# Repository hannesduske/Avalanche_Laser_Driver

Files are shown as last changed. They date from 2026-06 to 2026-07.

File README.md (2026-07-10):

# Nanosecond Avalanche Laser Driver

This avalanche driver generates $\mathbf{2-3\ \mathrm{ns}}$ pulses with peak pulse currents up to $\mathbf{150\ \mathrm{A}}$.
The driver integrates an adjustable boost converter to generate up to $\mathbf{320\ \mathrm{V}}$ from a low-voltage supply.

<div align="center">
<table style="border: none;">
  <tr>
    <td style="text-align:center">
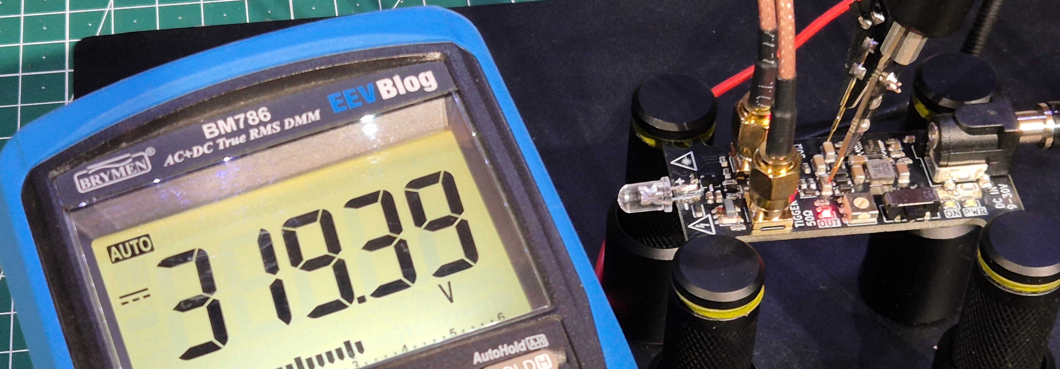
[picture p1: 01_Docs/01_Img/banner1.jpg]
      <br>
    </td>
    <td style="text-align:center">
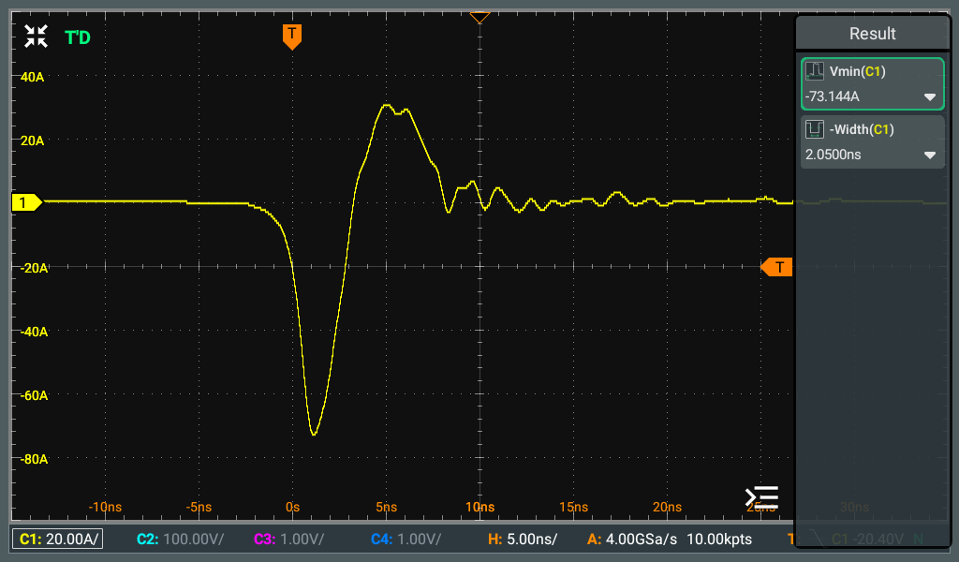
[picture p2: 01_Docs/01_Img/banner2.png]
      <br>
    </td>
  </tr>
</table>
</div>

## ⚠️ Safety Warning

**This project involves high-voltage electronics, high peak currents, and potentially hazardous laser radiation. Anyone building, modifying, or operating this design is responsible for understanding and managing these risks.**

> ⚠️ This repository contains engineering documentation and experimental hardware designs.
> It is not a certified, production-ready, or safety-tested device.

> ⚠️ The circuit contains hazardous high voltages, stored energy, and extremely high peak currents.
> Dangerous voltages may remain present even after the power source has been disconnected.

> ⚠️ Laser diodes driven by this circuit may emit optical pulses capable of causing immediate and permanent eye injury.
> Depending on the laser diode used, hazardous radiation may be invisible.

> ⚠️ Never operate this circuit without appropriate laser safety procedures, protective eyewear suitable for the wavelength used, and adequate electrical safety precautions.

<div align="center">
<table style="border: none;">
  <tr>
    <td style="text-align:center">
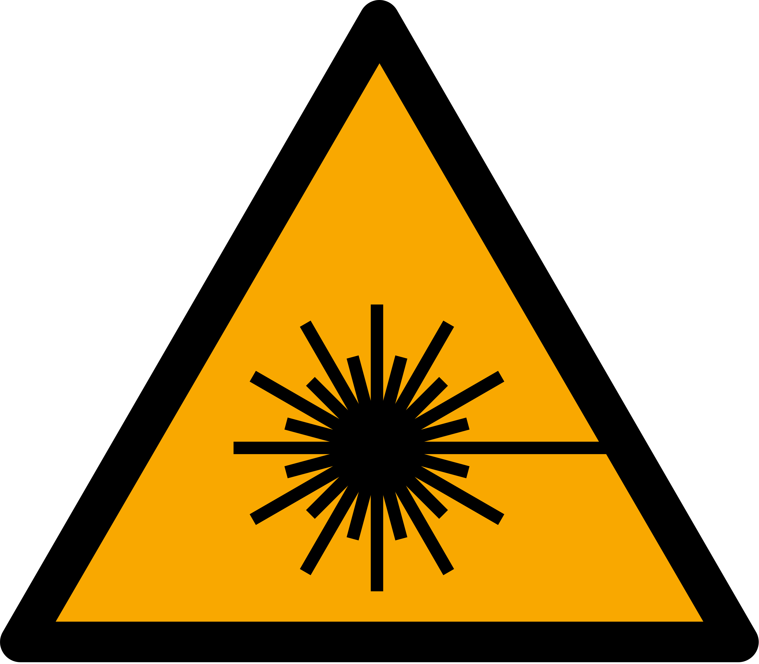
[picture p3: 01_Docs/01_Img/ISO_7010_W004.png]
      <br>
    </td>
    <td style="text-align:center">
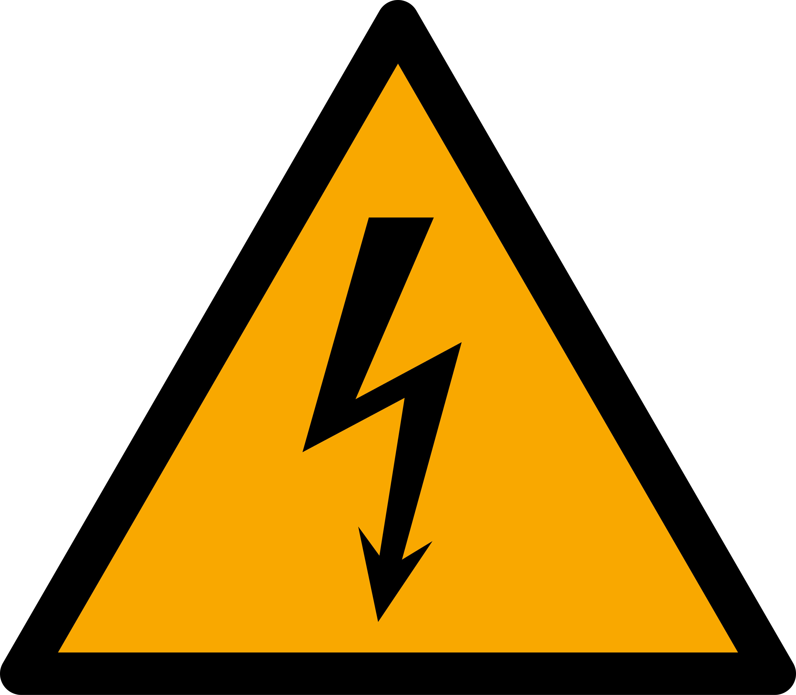
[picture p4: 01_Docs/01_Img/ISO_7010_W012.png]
      <br>
    </td>
  </tr>
</table>

**Refer to [this explicit safety statement](SAFETY.md) for more information.**

</div>

## Table of Contents

- [1. Technical Specification](#1-technical-specification)
  - [1.1 Key Features](#11-key-features)
  - [1.2 Design Specification](#12-design-specification)
  - [1.3 Measured Performance](#13-measured-performance)
- [2. Circuit Design](#2-circuit-design)
  - [2.1 Overview](#21-overview)
  - [2.2 Input Protection](#22-input-protection)
  - [2.3 Boost Converter](#23-boost-converter)
  - [2.4 Avalanche Output Stage](#24-avalanche-output-stage)
  - [2.5 Trigger Input Stage](#25-trigger-input-stage)
- [3. PCB Layout](#3-pcb-layout)
  - [3.1 Physical Dimensions](#31-physical-dimensions)
  - [3.2 Peripheral Components](#32-peripheral-components)
  - [3.3 Assembled Driver Boards](#33-assembled-driver-boards)
- [4. Driver Performance](#4-driver-performance)
  - [4.1 Output Voltage](#41-output-voltage)
  - [4.2 Short Circuit Test](#42-short-circuit-test)
  - [4.3 Blue LED Performance](#43-blue-LED-performance)
  - [4.4 PLPT9 450LC_E Performance](#44-plpt9-450lc_e-performance)
- [5. Protective Cover](#5-protective-cover)
- [6. References](#6-references)
  - [6.1 Datasheets of Main Components](#61-datasheets-of-main-components)
  - [6.2 Reference Designs](#62-reference-designs)
  - [6.3 General Resources](#63-general-resources)
  - [6.4 Design Tools](#64-design-tools)

## 1. Technical Specification

### 1.1 Key Features

This driver circuit is built around the [FMMT417](https://www.diodes.com/datasheet/download/FMMT417.pdf) avalanche transistor and is designed to operate up to the transistor's collector-emitter voltage rating of $320\ \mathrm{V}$.
The high voltage is generated by an integrated [LT8365](https://www.analog.com/media/en/technical-documentation/data-sheets/lt8365.pdf) boost converter and can be adjusted from $160\ \mathrm{V}$ to $320\ \mathrm{V}$ to control the output pulse current.

The driver is externally triggered through a transformer-isolated $50\ \Omega$ input.
The trigger signal is internally buffered, significantly improving output pulse consistency across a wide range of trigger amplitudes and waveforms.

For monitoring the generated output pulses, the driver includes a current-sense output with a sensitivity of $100\ \mathrm{A/V}$, enabling direct observation and measurement of the output pulse waveform.

### 1.2 Design Specification

<div align="center">

| Parameter | Value |
|-|-|
| Input Voltage | $9\ \mathrm{V}$ to $30\ \mathrm{V}$ |
| Output Voltage | $160\ \mathrm{V}$ to $320\ \mathrm{V}$ |
| Output Capacitance | $200\ \mathrm{pF}$ | 
| Current Sense Output | $100\ \mathrm{A}/\mathrm{V}$ into a $50\ \Omega$ load|
| Input Protection | Reverse voltage protection <br> Short-circuit protection |
| Trigger Input | $50\ \Omega$ Input <br> Internally buffered <br> Transformer-isolated <br> Immune to DC trigger signals |

</div>

> ℹ️ The upper voltage limit is chosen to match the FMMT417's collector-emitter voltage rating of $320\ \mathrm{V}$.

> ℹ️ The actual cutoff voltage of the driver input is $7.5\ \mathrm{V}$, but it is not guaranteed that the boost converter can reach its maximum output voltage with inputs below $9\ \mathrm{V}$.

### 1.3 Measured Performance

<div align="center">

| Parameter | Value |
|-|-|
| Shortest Pulse Width | $2\ \mathrm{ns}$ |
| Maximum Pulse Current | $150\ \mathrm{A}$ |
| Minimum Avalanche Voltage | $215\ \mathrm{V}$|
| Parasitic Output Inductance | $5.5\ \mathrm{nH}$ |
| Maximum Frequency | $20\ \mathrm{kHz}$ |

</div>

> ℹ️ The maximum frequency can be increased by replacing the $47\ \mathrm{k}\Omega$ charge current-limiting resistor with a smaller one.
Read [this](#42-short-circuit-test) for details.

## 2. Circuit Design

### 2.1 Overview

<div align="center">
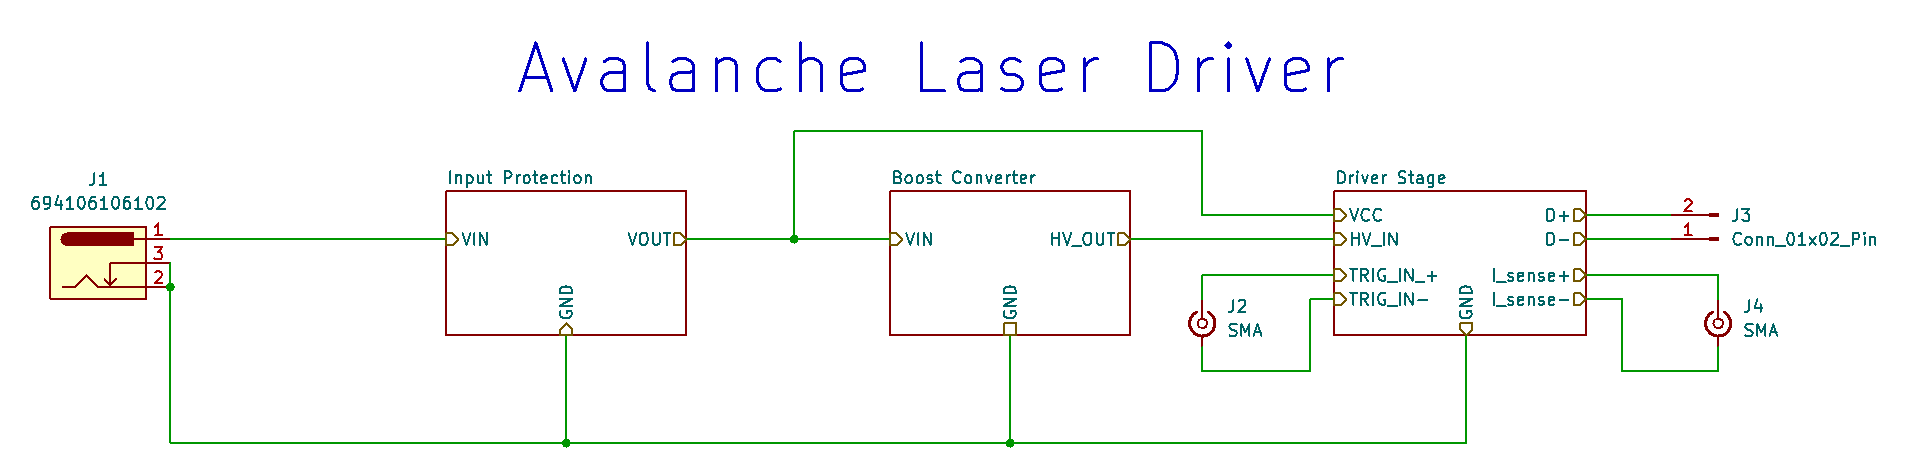
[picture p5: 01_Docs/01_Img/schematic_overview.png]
  <br>
</div>

The complete schematic is available [here](01_Docs/02_Schematic/avalanche_laser_driver_v0_2.pdf) as PDF.

### 2.2 Input Protection

<div align="center">
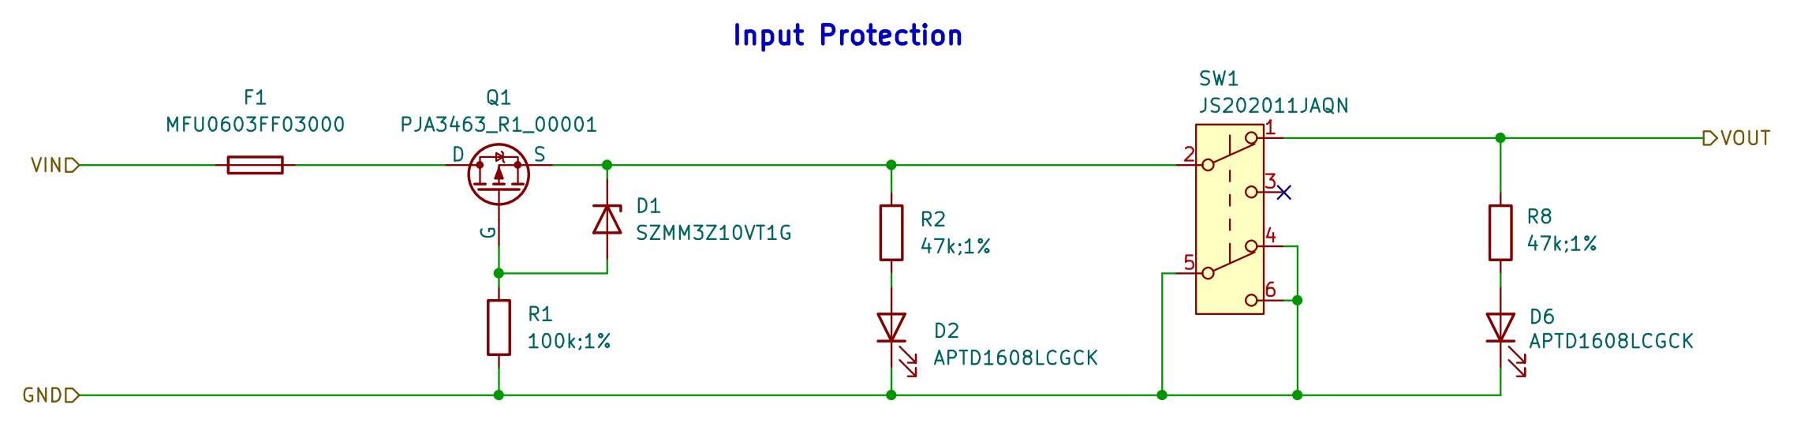
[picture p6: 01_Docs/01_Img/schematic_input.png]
  <br>
</div>

The driver is protected against reverse input voltages through MOSFET $\mathrm{Q1}$.
Additionally, the input stage includes an SMD fuse for short-circuit protection.
A switch is added to physically turn the driver on and off.
Two green LEDs indicate whether the DC input is connected correctly and whether the switch is turned on.

### 2.3 Boost Converter

<div align="center">
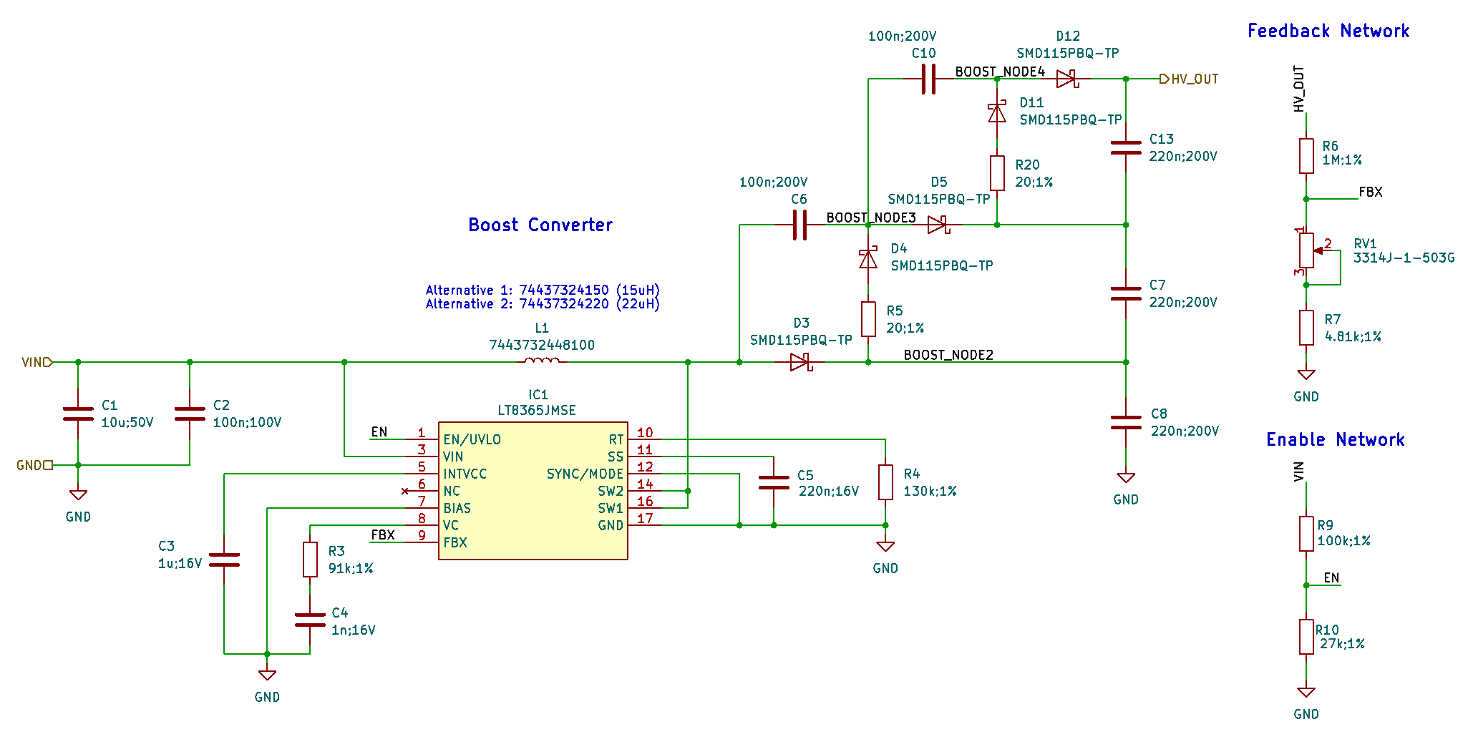
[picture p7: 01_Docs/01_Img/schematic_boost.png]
  <br>
</div>

The high voltage output is generated with an LT8365 boost converter.
Two diode-capacitor stages are added to the output of the boost converter to reach the voltage rating of the FMMT417.
The two additional stages reduce the current available for charging the output capacitors and the output charging resistor $\mathrm{R12}$ is sized accordingly.

The output voltage is set by the feedback network formed by $\mathrm{R5}$, $\mathrm{R7}$ and $\mathrm{RV1}$.
The ratio of $\mathrm{R5}$ to $\mathrm{R7}$ sets the maximum output voltage $\mathrm{HV\_OUT}$ and $\mathrm{R7}$ is tuned to achieve a $320\ \mathrm{V}$ output with the assembled circuit.
The theoretical maximum voltage with the selected values $\mathrm{R5}=1\ \mathrm{M}\Omega$ and $\mathrm{R7}=4.81\ \mathrm{k}\Omega$ is $334\ \mathrm{V}$.

The potentiometer $\mathrm{RV1}$ sets the adjustment range of the output voltage.
It should cover the entire range from the FMMT417's minimum avalanche voltage (around $215\ \mathrm{V}$) to its collector-emitter voltage rating of $320\ \mathrm{V}$.
The chosen value of $5\ \mathrm{k}\Omega$ is larger than necessary for that purpose, as it gives a lower voltage limit of $160\ \mathrm{V}$.
Using a smaller value potentiometer (around $3.3\ \mathrm{k}\Omega$) would enable finer adjustments while still covering the entire voltage range.

The third terminal of $\mathrm{RV1}$ is also connected so that, if the potentiometer wiper fails open-circuit, the potentiometer defaults to its maximum resistance.
In that case the boost converter falls back to its minimum output voltage.

A red LED indicates whether the boost converter output capacitors are charged.

### 2.4 Avalanche Output Stage

<div align="center">
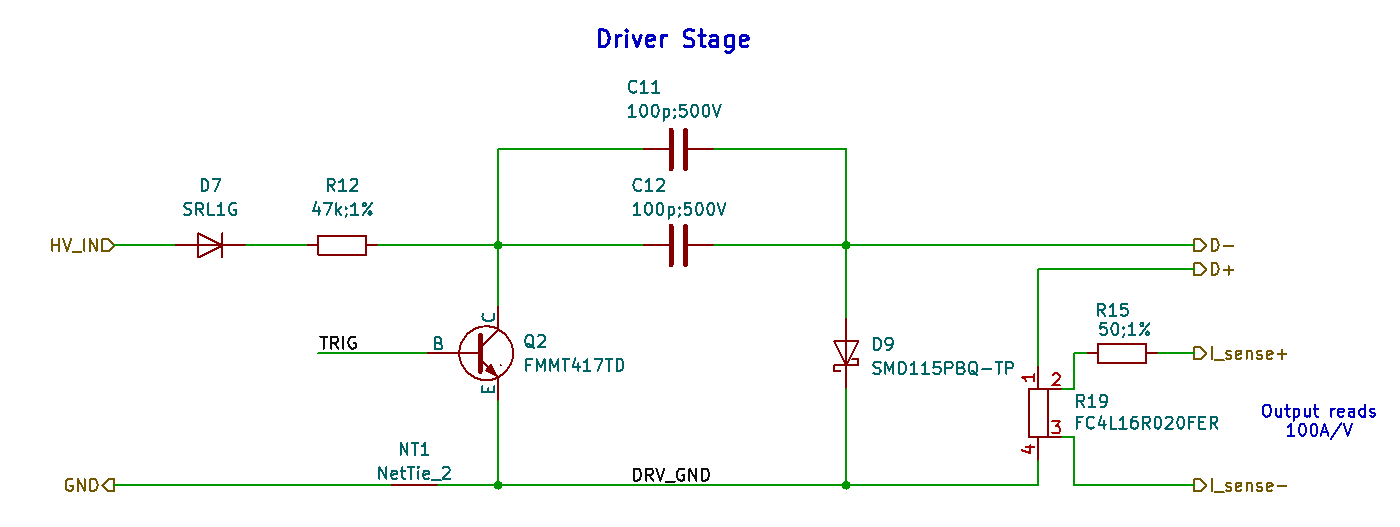
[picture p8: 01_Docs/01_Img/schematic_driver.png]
  <br>
</div>

The core of this driver is a basic avalanche transistor circuit.
The high voltage output capacitors $\mathrm{C11}$ and $\mathrm{C12}$ are charged through the current-limiting resistor $\mathrm{R12}$ and the charging diode $\mathrm{D9}$.
Once charged, a small signal at the base of the transistor $\mathrm{Q2}$ initiates avalanche breakdown across the collector-emitter junction, resulting in the rapid discharge of $\mathrm{C11}$ and $\mathrm{C12}$ through the output load.
After an output pulse the capacitors recharge again.

One goal of the output stage is to minimize the parasitic inductance as it is the main limiting factor for the peak pulse current during fast transients.
Therefore, multiple smaller output capacitors in parallel are preferred over a single large one because the effective equivalent series inductance (ESL) is reduced.
In this design two $100\ \mathrm{pF}$ 0603 capacitors are used, as the only other smaller capacitors with sufficient current rating ($47\ \mathrm{pF}$) were not in stock at the time the driver boards were assembled.

The components $\mathrm{C11}$, $\mathrm{C12}$ and $\mathrm{R12}$ form an RC low-pass which sets the maximum frequency at which the circuit can be triggered.
Assuming that approximately three time constants are required for capacitor recharge, the maximum frequency is approximately $f_{max}\approx \frac{1}{3\cdot \mathrm{R_{12}}(\mathrm{C_{11}}+\mathrm{C_{12}})} = \frac{1}{3 \cdot 47\ \mathrm{k}\Omega(100\ \mathrm{pF}+100\ \mathrm{pF})} \approx 35\ \mathrm{kHz}$.
The actual frequency is lower than that because the capacitors do not start charging immediately after a pulse, as is shown by the measurements below.

In this design the driver capacitance is $200\ \mathrm{pF}$ with a maximum output voltage of $320\ \mathrm{V}$.
The maximum stored electrical energy per pulse is $E_p=\frac{1}{2}\cdot C \cdot U^2=\frac{1}{2}\cdot 200\ \mathrm{pF} \cdot (320\ \mathrm{V})^2=10.24\ \mu\mathrm{J}$.
With the maximum achievable trigger frequency of $20\ \mathrm{kHz}$ (see measurements below) the maximum theoretical average output power is approximately $P=E_p\cdot f=10.24\ \mu\mathrm{J}\cdot 20\ \mathrm{kHz}=205\ \mathrm{mW}$

The $20\ \mathrm{m}\Omega$ four-terminal shunt resistor $\mathrm{R19}$ is placed in series with the driver output, enabling the pulse current to be monitored.
This low-value resistor has a minimal effect on the pulse current while providing accurate measurements through its two sense terminals.
The circuit's sense output is designed to drive a $50\ \Omega$-terminated oscilloscope input.
Together with the external $50\ \Omega$ termination resistor, the internal $50\ \Omega$ resistor $\mathrm{R15}$ forms a $1:2$ voltage divider.
The $20\ \mathrm{m}\Omega$ shunt resistor provides a sensitivity of $20\ \mathrm{mV/A}$.
This is halved by the voltage divider, resulting in a final sensitivity of $10\ \mathrm{mV/A}$ or $100\ \mathrm{A/V}$ at the circuit's current sense output.

### 2.5 Trigger Input Stage

<div align="center">
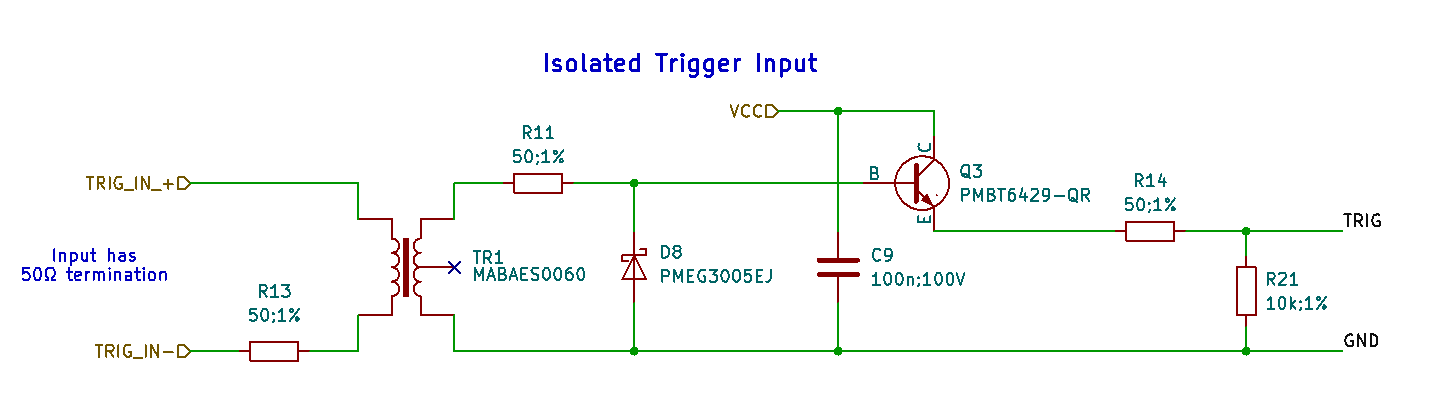
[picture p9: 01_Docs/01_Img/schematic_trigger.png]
  <br>
</div>

The trigger input feeds a $50\ \Omega$ terminated balun transformer $\mathrm{TR1}$ for isolation and for high-pass filtering of the input.
The transformed signal is then buffered by the high-speed BJT $\mathrm{Q3}$ which is connected to the FMMT417's base through the current-limiting resistor $\mathrm{R14}$.
The pull-down resistor $\mathrm{R21}$ helps turn off $\mathrm{Q2}$ rapidly after an avalanche and prevents accidental triggering caused by a floating base.

The high-pass property of the balun transformer also prevents damage to $\mathrm{Q2}$ from DC input signals which would otherwise keep the avalanche transistor turned on.

## 3. PCB Layout

### 3.1 Physical Dimensions

Below is an illustration of the physical outline and hole spacing of the PCB V0.2.
The mounting holes fit the standard $25\ \mathrm{mm}$ hole pattern of optical benches.

<div align="center">
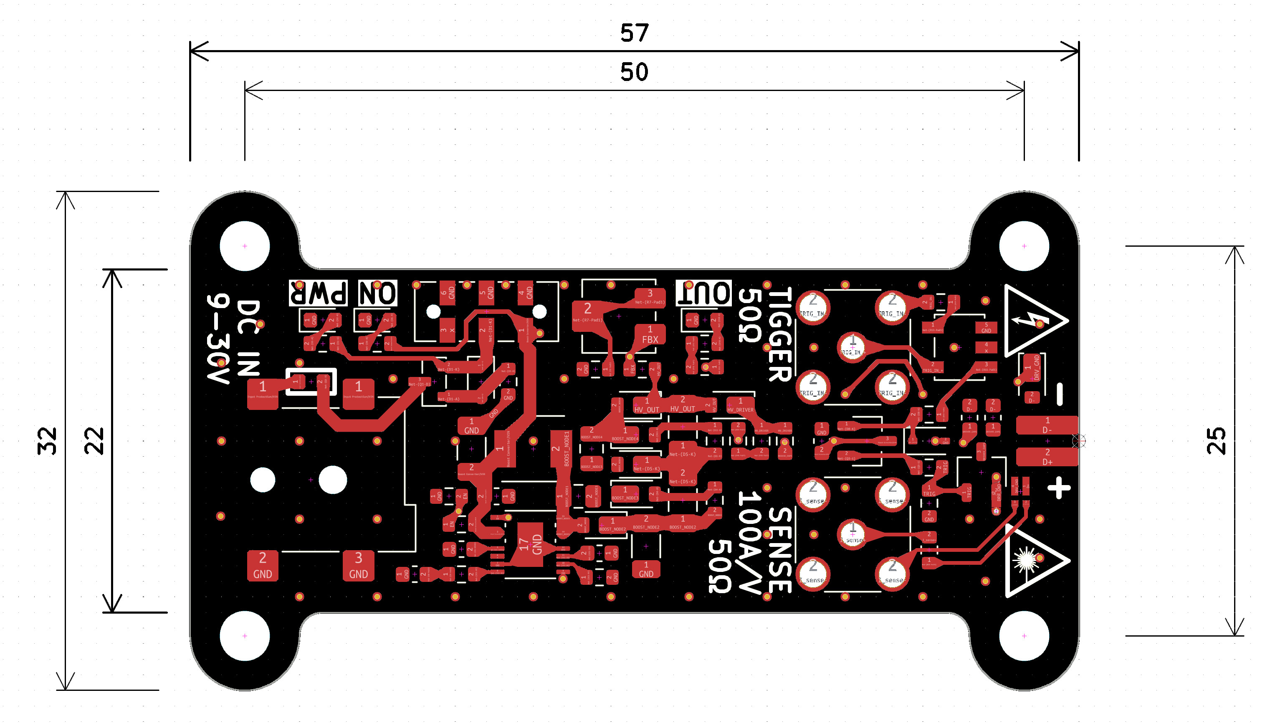
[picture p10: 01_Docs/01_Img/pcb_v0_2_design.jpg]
  <br>
</div>

### 3.2 Peripheral Components

Below is a functional description of the main peripheral components of the PCB.

<div align="center">
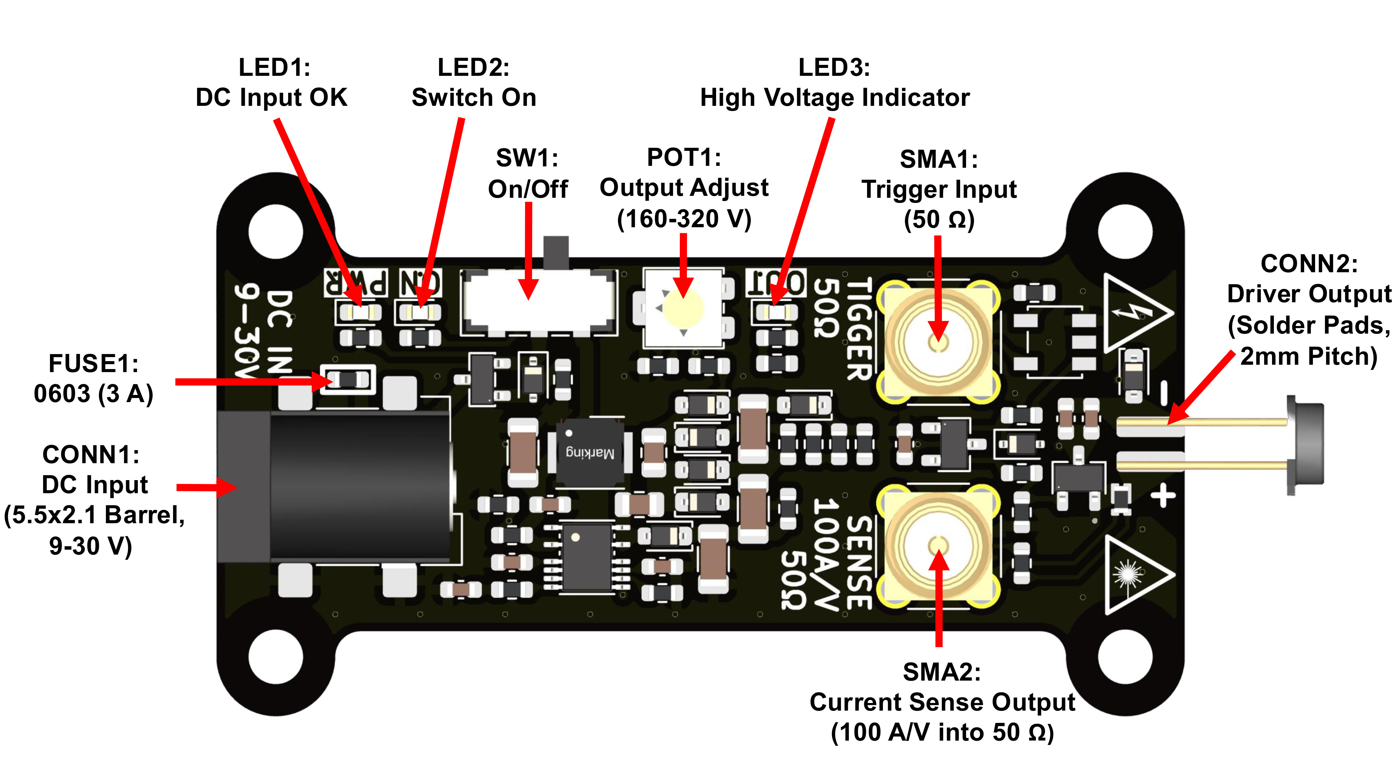
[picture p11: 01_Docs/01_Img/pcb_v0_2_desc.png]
<br>

| Reference | Description |
|-|-|
| SW1 | On/off switch. Switches the supply rail of the boost converter. |
| POT1  | Output voltage adjustment. |
| LED1  | Indicates DC input is connected. |
| LED2  | Indicates the boost converter is supplied. Lights up when SW1 is on. |
| LED3  | Indicates the boost converter output caps are charged. | 
| SMA1  | Trigger input ($50\ \Omega$). | 
| SMA2  | Current sense output ($50\ \Omega$). |
| CONN1 | DC input. 5.5 x 2.1 mm barrel jack (center positive). |
| CONN2 | Driver output. Solder pads ($2\ \mathrm{mm}$ pitch). |
| FUSE1 | 0603 SMD Fuse ($3\ \mathrm{A}$) for short-circuit protection. |
</div>

### 3.3 Assembled Driver Boards

The two driver boards shown below were assembled for a performance test.
The left driver was assembled with an ams OSRAM PLPT9 450LC_E laser diode and the right one with a blue LED.

<div align="center">
<table style="border: none;">
  <tr>
    <td style="text-align:center">
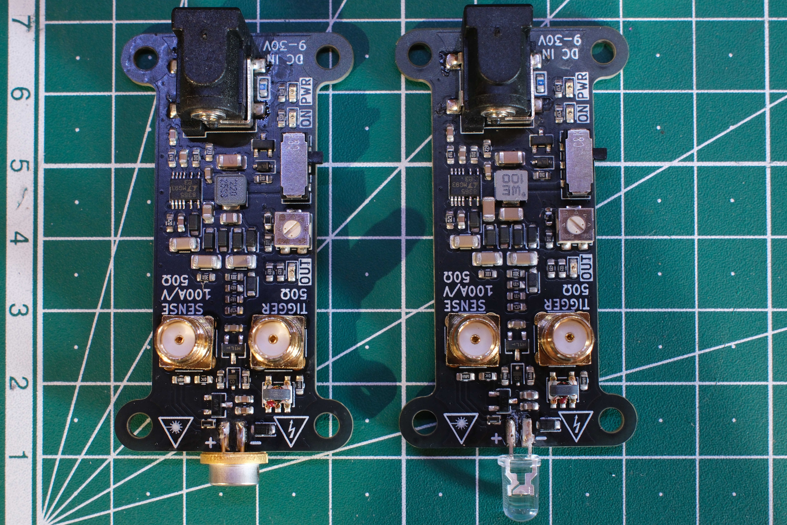
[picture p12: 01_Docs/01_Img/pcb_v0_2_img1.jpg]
      <br>
      <p>Top view of the V0.2 PCBs</p>
    </td>
    <td style="text-align:center">
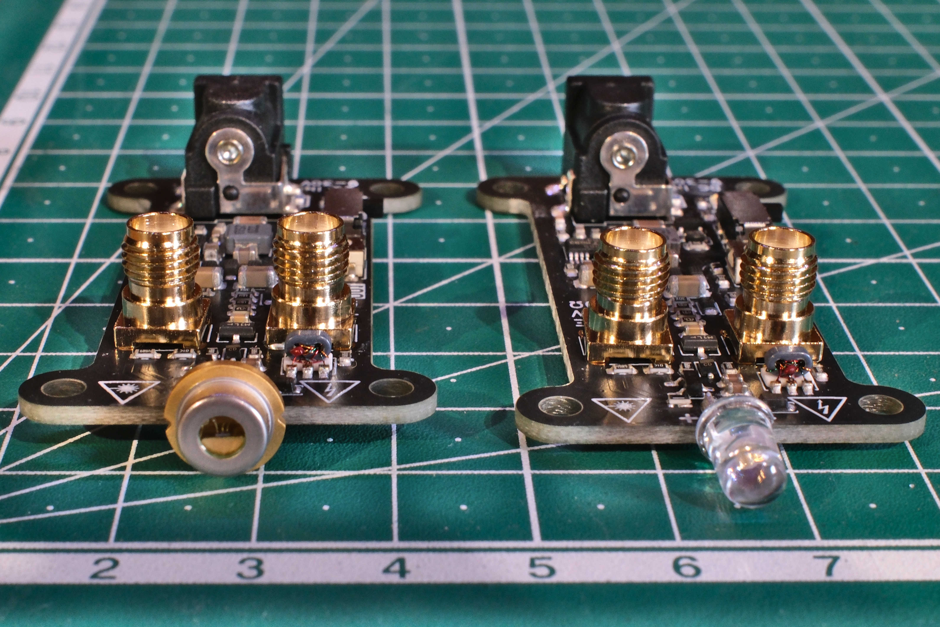
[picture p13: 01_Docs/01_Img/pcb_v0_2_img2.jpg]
        <br>
      <p>Front view of the V0.2 PCBs</p>
    </td>
  </tr>
</table>
</div>

## 4. Driver Performance

Driver performance was evaluated using the following configurations:
- Output pads shorted with solder bridge
- Blue LED (right PCB in above pictures)
- ams OSRAM PLPT9 450LC_E (left PCB in above pictures)

### 4.1 Output Voltage

The output voltage of the driver is adjustable between $160\ \mathrm{V}$ and $320\ \mathrm{V}$.

<div align="center">
<table style="border: none;">
  <tr>
    <td style="text-align:center">
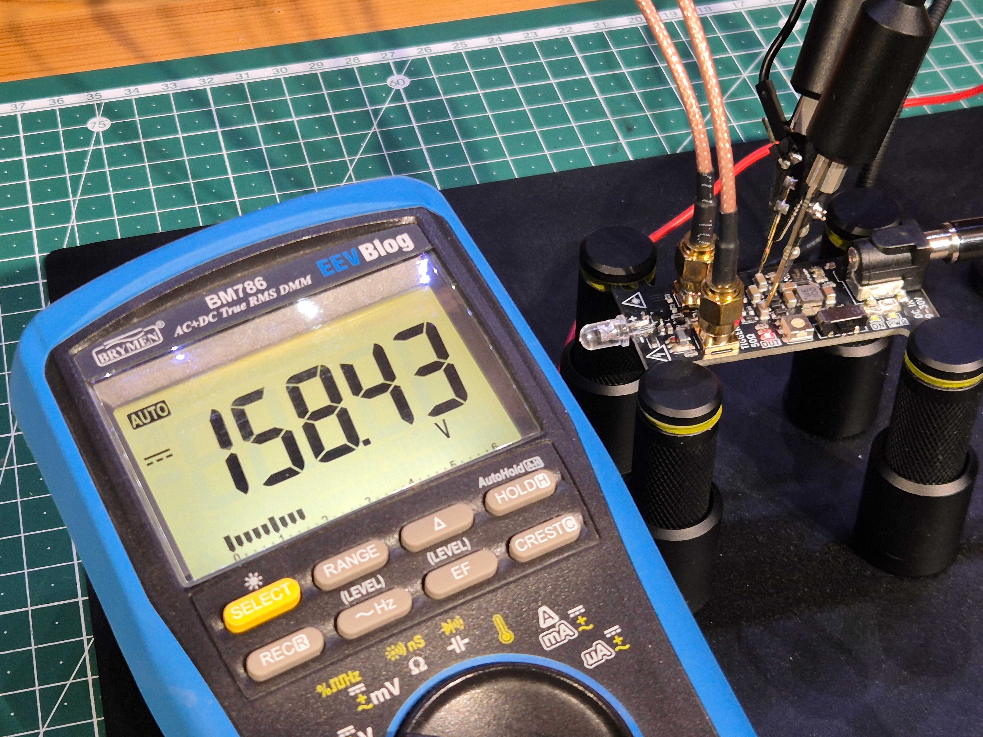
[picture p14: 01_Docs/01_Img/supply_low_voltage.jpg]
      <br>
      <p>Lower voltage limit of the boost converter</p>
    </td>
    <td style="text-align:center">
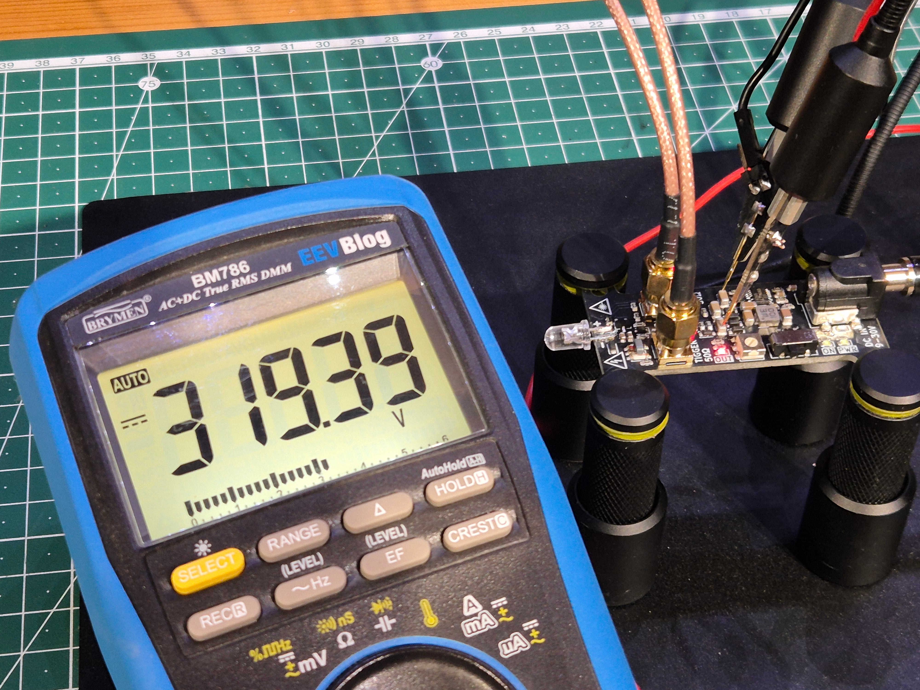
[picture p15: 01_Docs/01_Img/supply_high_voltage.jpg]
        <br>
      <p>Upper voltage limit of the boost converter</p>
    </td>
  </tr>
</table>
</div>

> ⚠️ The feedback resistors should not be replaced to increase the upper voltage limit above $320\ \mathrm{V}$.
> Increasing the output voltage risks instant destruction of the FMMT417.

### 4.2 Short-Circuit Test

In the first test the output pads of the driver are shorted with a solder bridge.
The output is set to $320\ \mathrm{V}$ and the trigger signal is a $2\ \mathrm{Vpp}$ square wave.

<div align="center">
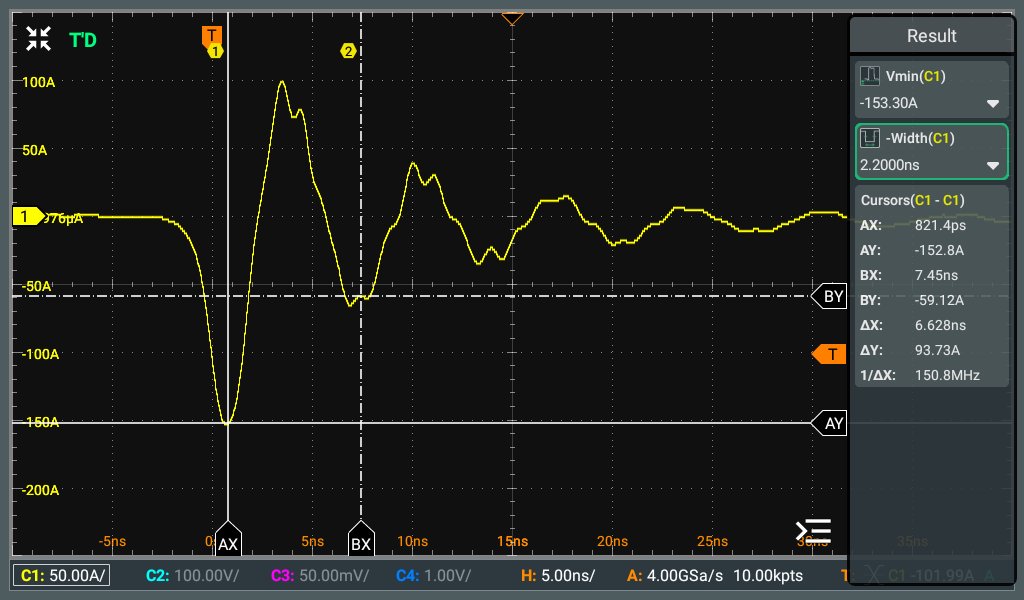
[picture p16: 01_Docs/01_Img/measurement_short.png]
  <br>
  <p>Short-circuit test at 320 V with a 2 Vpp trigger signal</p>
</div>

The short-circuit test shows that the output oscillates with no load connected.
This is the expected behavior, because the stored energy is dissipated only slowly through the parasitic impedance of the circuit and there is no diode that blocks reverse current.

In the short-circuit test we measured a maximum current of $153\ \mathrm{A}$ with a pulse width of $2.2\ \mathrm{ns}$.

The minimum operating voltage at which avalanche triggering occurs was measured to be 215 V with a 5 V square wave trigger signal.
Note that the minimum voltage depends on the trigger signal amplitude.
The lower the output voltage, the larger the trigger signal amplitude must be to start an avalanche.

We can also approximate the effective parasitic loop inductance of the output stage from the observed oscillation.
For this, we assume an LC oscillator with a frequency of $f = \frac{1}{2 \pi \sqrt{LC}}$.
From the measured oscillation frequency we get $f = 152\ \mathrm{MHz}$ and the output capacitance is $200\ \mathrm{pF}$.
With these values we calculate an inductance of $L = \frac{1}{C(2\pi f)^2} = \frac{1}{200\ \mathrm{pF}(2\pi \cdot 152\ \mathrm{MHz})^2} = 5.46\ \mathrm{nH}$.

<div align="center">
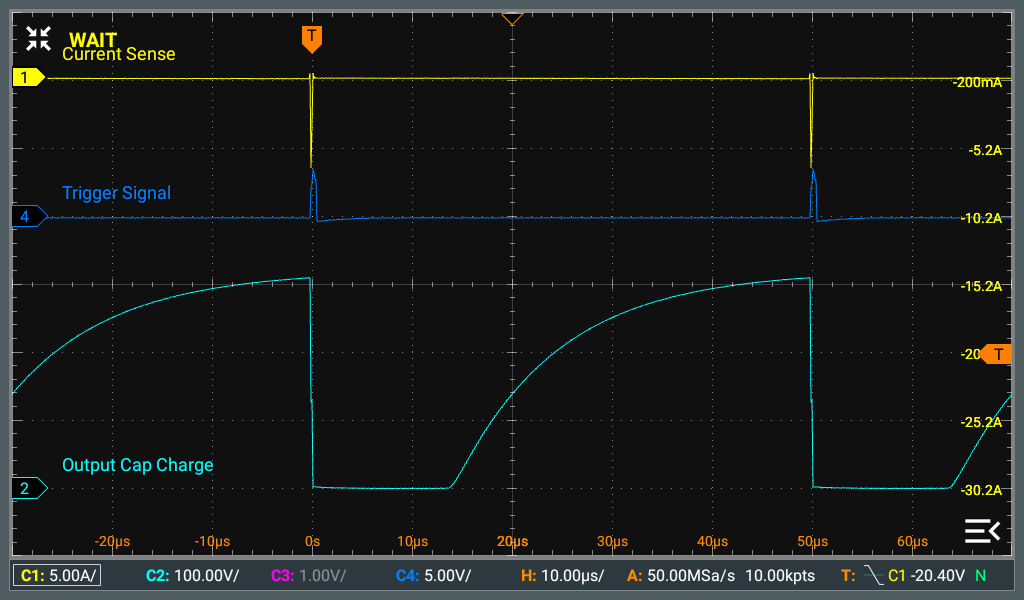
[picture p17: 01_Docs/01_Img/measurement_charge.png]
  <br>
  <p>Measurement of the output capacitor charge time</p>
</div>

In a second measurement the maximum trigger frequency is tested.
The measurement shows that the output capacitors start charging only after a delay of $14\ \mathrm{\mu s}$.
This reduces the actual achievable output frequency from the theoretical $35\ \mathrm{kHz}$ to a practically achievable frequency of $20\ \mathrm{kHz}$.

### 4.3 Blue LED Performance

In the second test the output drives a blue LED.
The output is set to $320\ \mathrm{V}$ and the trigger signal is a $2\ \mathrm{Vpp}$ square wave.

<div align="center">
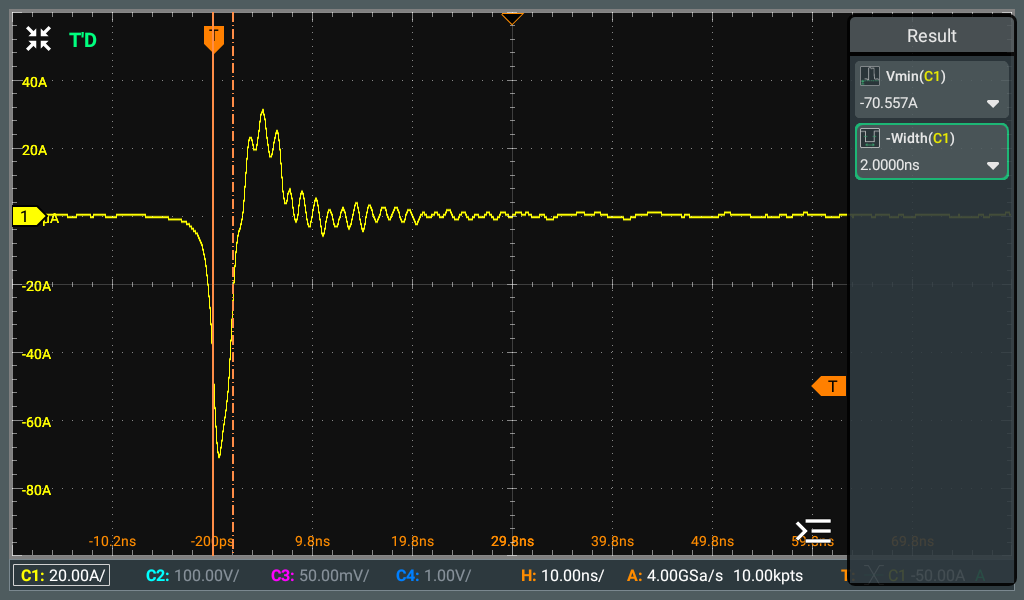
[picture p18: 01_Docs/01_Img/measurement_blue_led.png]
  <br>
  <p>Test with blue LED at 320 V with a 2 Vpp trigger signal</p>
</div>

With the blue LED, the output pulse is significantly different compared to the short-circuit test.
There is a large, narrow current pulse across the diode, followed by a smaller, wider pulse in the reverse direction.

With the blue LED, the maximum current is $70\ \mathrm{A}$ with a $2\ \mathrm{ns}$ pulse width.

### 4.4 PLPT9 450LC_E Performance

In the third test the output drives an ams OSRAM PLPT9 450LC_E.
The output is set to $320\ \mathrm{V}$ and the trigger signal is a $2\ \mathrm{Vpp}$ square wave.

<div align="center">
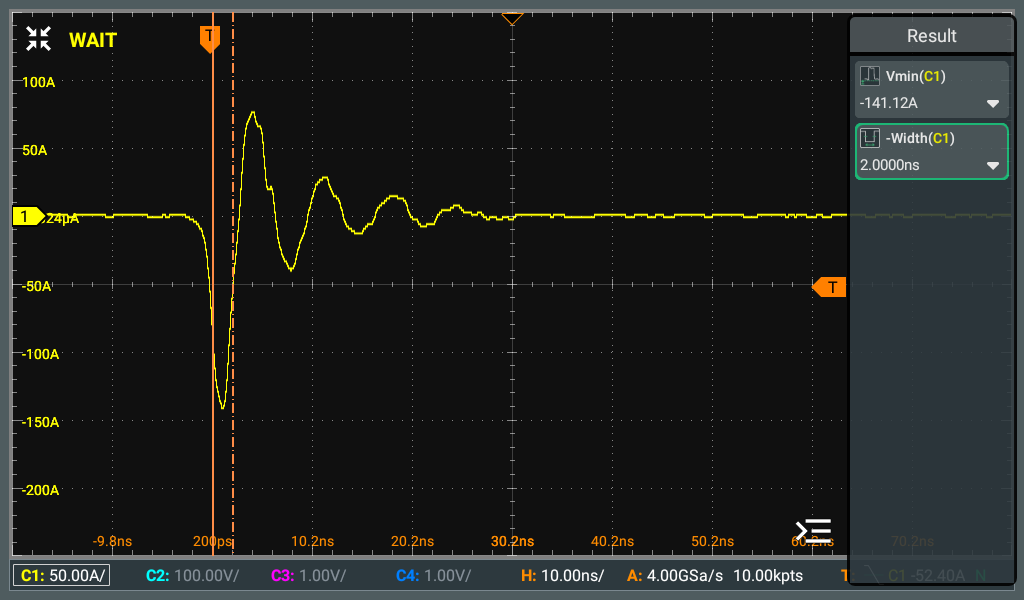
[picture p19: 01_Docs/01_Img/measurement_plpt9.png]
  <br>
  <p>Test with PLPT9 450LC_E at 320 V with a 2 Vpp trigger signal</p>
</div>

With the PLPT9 laser diode the maximum current is $141\ \mathrm{A}$ with a $2\ \mathrm{ns}$ pulse width.

Note that the oscillation is less damped compared to that of the blue LED and more similar to the short-circuit test.
Presumably this is because of the integrated reverse-protection Zener diode in the PLPT9 package which protects the sensitive main laser diode against reverse currents.
It would be interesting to see how this oscillatory behavior actually influences the optical pulse shape of the PLPT9 laser.

Similar to the short-circuit test the oscillation frequency is approximately 150 MHz.

## 5. Protective Cover

A 3D printed cover has been designed for the driver.
It covers the high voltage components and exposes only the peripherals.

The cover is available in two variants.
A monolithic version that is easy to print and a version with **T**rigger/ **S**ense markings for printers with filament change capability.

<div align="center">
<table style="border: none;">
  <tr>
    <td style="text-align:center">
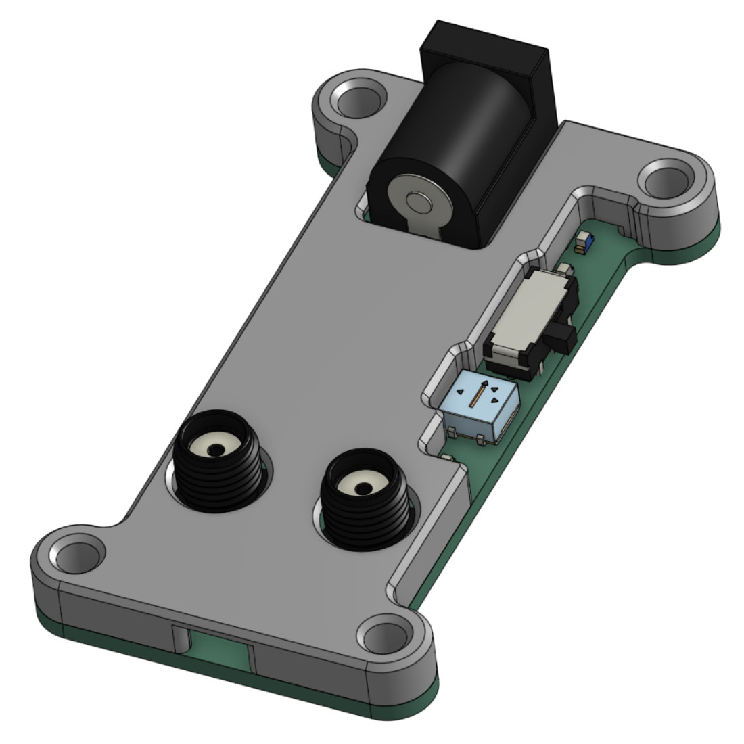
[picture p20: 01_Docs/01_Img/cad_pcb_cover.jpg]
      <br>
      <p>Monolithic cover</p>
    </td>
    <td style="text-align:center">
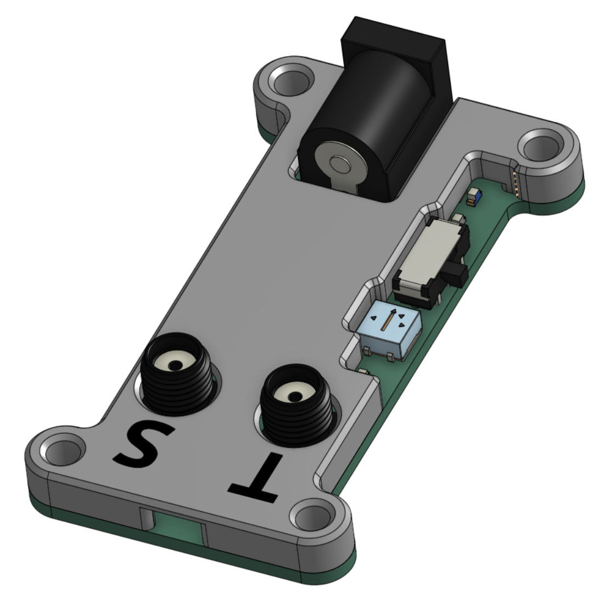
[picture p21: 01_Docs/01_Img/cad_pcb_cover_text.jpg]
      <br>
      <p>Cover with Trigger/ Sense markings</p>
    </td>
  </tr>
</table>
</div>

## 6. References
### 6.1 Datasheets of Main Components
- [LT8365](https://www.analog.com/media/en/technical-documentation/data-sheets/lt8365.pdf) Boost converter
- [FMMT417](https://www.diodes.com/datasheet/download/FMMT417.pdf) Avalanche transistor
- [PLPT9 450LC_E](https://look.ams-osram.com/m/8992eec443b4ce2/original/PLPT9-450LC_E.pdf) ams OSRAM Laser Diode

### 6.2 Reference Designs
- [Les' Lab Laser Driver](https://github.com/leswright1977/avalanche-laser-diode-driver) + [Video](https://www.youtube.com/watch?v=3-htF8Jrixo&t=24s) (ZTX415/ 2N5192G)
- [BigPulse Driver](https://github.com/MazinLab/BigPulse) + [Video](https://www.youtube.com/watch?v=OXhiX0EW5MI) (FMMT415TD + LT8365)

### 6.3 General Resources
- Lasercomponents [Whitepaper](https://www.lasercomponents.com/uk/photonics-portal/knowledge-center/whitepapers/drive-electronics-for-pulsed-laser-diodes/)
- Zetex ZTX415 [Application Note AN8](https://user-web.icecube.wisc.edu/~kitamura/NK/Flasher_Board/Useful/research/AN8.pdf)
- Jim Williams Pulser [AN47 Appendix D (p. 93)](https://www.analog.com/media/en/technical-documentation/application-notes/an47fa.pdf)
- Selection and usage of laser safety goggles [DGUV 203-042](https://publikationen.dguv.de/widgets/pdf/download/article/249) (German)
- Continuous wave laser diodes enable fast optoacoustic imaging [ResearchGate](https://www.researchgate.net/publication/321863583_Continuous_wave_laser_diodes_enable_fast_optoacoustic_imaging)

### 6.4 Design Tools
- [LTSpice](https://www.analog.com/en/resources/design-tools-and-calculators/ltspice-simulator.html) Circuit simulation
- [KiCad 10](https://www.kicad.org/blog/2026/03/Version-10.0.0-Released/) Circuit board design
- [SMath Studio](https://smath.com/) Design calculations

## License

This project is licensed under the CERN Open Hardware Licence Version 2 - Permissive ([CERN-OHL-P](https://ohwr.org/cern_ohl_p_v2.txt)).

Third-party datasheets, logos, warning symbols, and referenced documentation remain the property of their respective owners.

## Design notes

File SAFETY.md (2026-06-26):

# Disclaimer

This project is provided for research and educational purposes only.

The design files, calculations, simulations, PCB layouts, measurements, and other documentation are provided "as is", without warranty of any kind, express or implied, including but not limited to warranties of merchantability, fitness for a particular
purpose, and non-infringement.

The authors cannot be held responsible for any injury, death, loss, damage, legal consequences, or other claims resulting from the construction, modification, testing, or use of this design.

By using any part of this project, you acknowledge that you understand the risks associated with high-voltage electronics and laser systems and accept full responsibility for your actions.

# Laser Hazard Notice

Pulse duration does not eliminate the risk of eye injury.

Even nanosecond optical pulses can exceed maximum permissible exposure limits by many orders of magnitude.
Peak optical power, wavelength, beam divergence, repetition rate, and exposure geometry all influence the hazard level.

The laser diode and driver combination may constitute a Class 3B or Class 4 laser system depending on operating conditions.
Laser systems based on this design should only be operated with suitable mechanical shielding, beam control measures, and safety interlocks where appropriate.

Users of this project are responsible for understanding the associated risks and for ensuring that their construction, testing, and operation methods are appropriate for the hazards involved.

# High Voltage and High Current Hazard Notice

This circuit generates and stores hazardous voltages and can discharge
energy through extremely low impedance paths.

The output stage is designed to produce very high peak currents with nanosecond-scale rise times.
Short pulse duration does not make the circuit safe.

The presence or absence of a power supply supply does not indicate the true hazard level of the circuit. The output capacitors may retain dangerous charge even after the power source has been disconnected.

**High-voltage hazards include:**

- Electric shock or electrocution
- Burns caused by electrical arcs or component failure
- Fire caused by insulation breakdown or short circuits
- Explosive failure of semiconductor devices, capacitors, or other
  components
- Damage to test equipment or measurement instruments

Never assume that the circuit is safe because it is turned off. Always discharge high-voltage storage components using appropriate methods and verify the absence of hazardous voltage before handling the circuit.

Use appropriate high-voltage insulation, clearances, protective equipment, and measurement tools rated for the voltages and transient conditions present.

# Measurement and Testing Notice

This circuit produces fast transient signals that may exceed the capabilities of standard laboratory equipment.

Incorrect measurement techniques may result in:

- Damage to oscilloscopes, probes, or other instruments
- Incorrect measurements leading to unsafe conclusions
- Unintended triggering or failure of the circuit

Only use measurement equipment, probes, fixtures and connection methods that are suitable for the voltage levels, bandwidth and transients of this driver circuit.

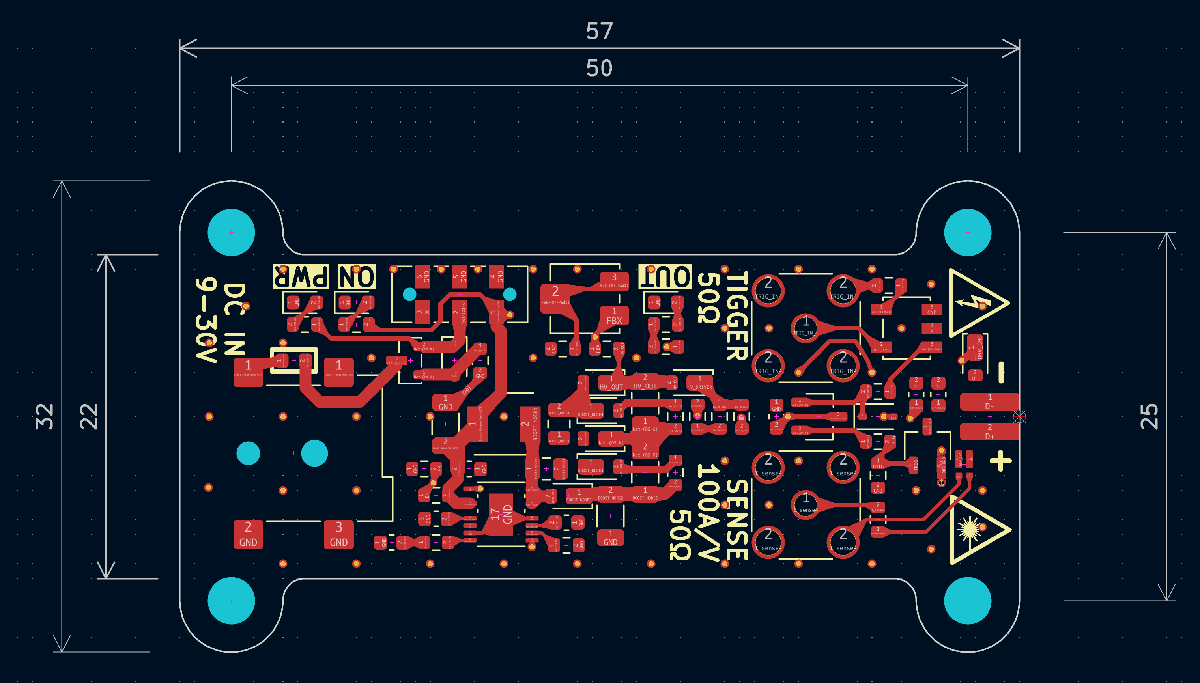
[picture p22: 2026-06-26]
01_Docs/01_Img/pcb_v0_2_design.png

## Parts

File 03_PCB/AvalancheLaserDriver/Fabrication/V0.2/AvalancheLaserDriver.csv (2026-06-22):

ID | Bezeichner | Footprint | Stückzahl | Bezeichnung | Anbieter und Referenz
1 | R15,R11,R14,R13 | R_0603_1608Metric | 4 | 50;1%
2 | R5,R20 | R_0603_1608Metric | 2 | 20;1%
3 | D8 | D_SOD-323 | 1 | PMEG3005EJ
4 | J1 | BarrelJack_Wuerth_694106106102_2.0x5.5mm | 1 | 694106106102
5 | C6,C10 | C_0805_2012Metric | 2 | 100n;200V
6 | C1 | C_1206_3216Metric | 1 | 10u;50V
7 | D2,D6 | LED_0603_1608Metric | 2 | APTD1608LCGCK
8 | R10 | R_0603_1608Metric | 1 | 27k;1%
9 | RV1 | Potentiometer_Bourns_3314J_Vertical | 1 | 3314J-1-473G
10 | Q3 | TSOT-23 | 1 | PMBT6429-QR
11 | R19 | FC4L16 | 1 | FC4L16R020FER
12 | R12,R8,R2 | R_0603_1608Metric | 3 | 47k;1%
13 | D5,D11,D9,D3,D4,D12 | D_SOD-323HE | 6 | SMD115PBQ-TP
14 | R1,R9 | R_0603_1608Metric | 2 | 100k;1%
15 | J3 | R_0815_2038Metric_Pad1.20x4.05mm_HandSolder | 1 | Conn_01x02_Pin
16 | R21 | R_0603_1608Metric | 1 | 10k;1%
17 | C4 | C_0603_1608Metric | 1 | 1n;16V
18 | D1 | D_SOD-323 | 1 | SZMM3Z10VT1G
19 | R16,R18,R17,R22 | R_0603_1608Metric | 4 | 160k;1%
20 | R4 | R_0603_1608Metric | 1 | 130k;1%
21 | C13,C8,C7 | C_1206_3216Metric | 3 | 220n;200V
22 | F1 | Fuse_0603_1608Metric | 1 | MFU0603FF03000
23 | L1 | L_Wurth_WE-LQSH-4020 | 1 | 7443732448100
24 | R3 | R_0603_1608Metric | 1 | 91k;1%
25 | C3 | C_0603_1608Metric | 1 | 1u;16V
26 | C5 | C_0603_1608Metric | 1 | 220n;16V
27 | C9,C2 | C_0603_1608Metric | 2 | 100n;100V
28 | R6 | R_0603_1608Metric | 1 | 1M;1%
29 | R7 | R_0603_1608Metric | 1 | 4.99k;1%
30 | Q1 | SOT-23 | 1 | PJA3463_R1_00001
31 | C12,C11 | C_0603_1608Metric | 2 | 100p;500V
32 | D10 | LED_0603_1608Metric | 1 | APTD1608LSURCK
33 | J4,J2 | SMA_Wurth_60312002114503_Vertical | 2 | SMA
34 | IC1 | Analog_MSOP-12-16-1EP_3x4.039mm_P0.5mm_EP1.651x2.845mm | 1 | LT8365JMSE
35 | Q2 | TSOT-23 | 1 | FMMT417TD
36 | SW1 | SW_DPDT_CK_JS202011JCQN | 1 | JS202011JAQN
37 | D7 | D_SOD-323HE | 1 | SRL1G
38 | TR1 | Transformer_MACOM_SM-22 | 1 | MABAES0060

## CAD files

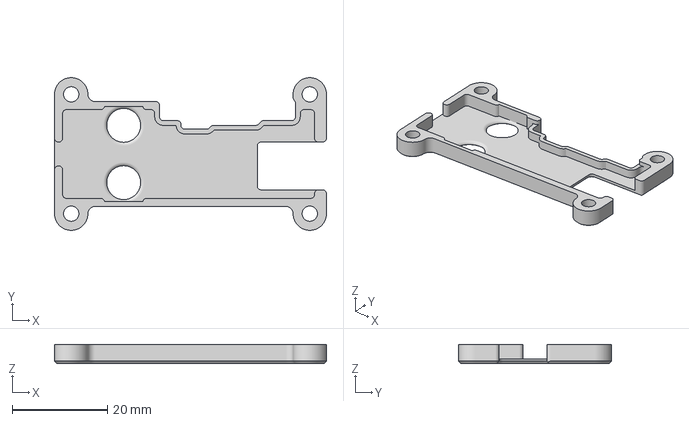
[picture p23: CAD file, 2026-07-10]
04_CAD/pcb_cover_text.3mf
57.0 x 32.0 x 4.00 mm

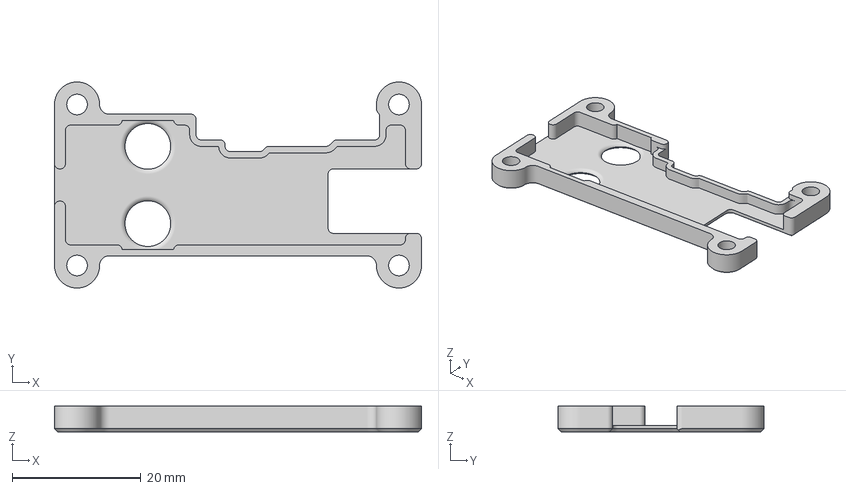
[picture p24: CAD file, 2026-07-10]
04_CAD/pcb_cover.3mf
57.0 x 32.0 x 4.00 mm

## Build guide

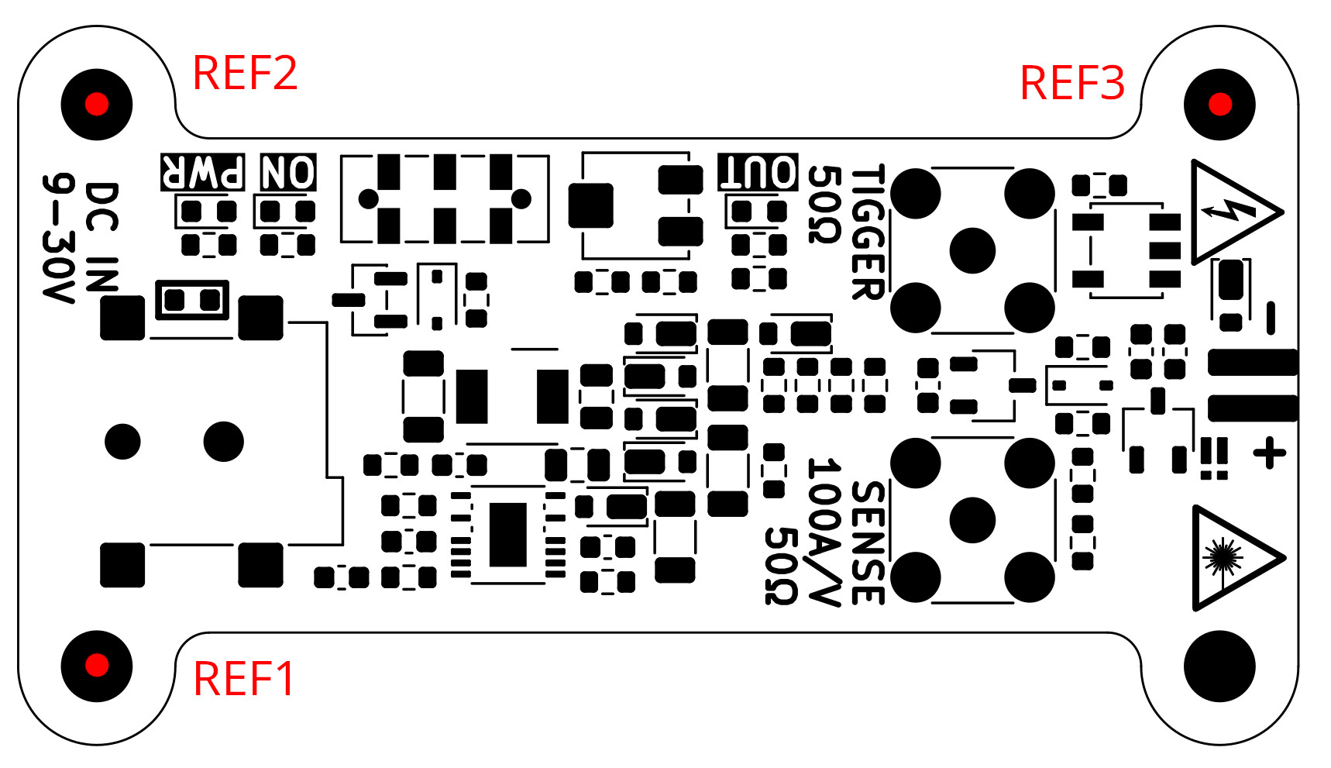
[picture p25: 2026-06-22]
03_PCB/AvalancheLaserDriver/Fabrication/V0.2/AvlanacheLaserDriver_V0_2.jpg

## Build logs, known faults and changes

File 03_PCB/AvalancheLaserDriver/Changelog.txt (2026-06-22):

Changelog
- V0.1
  - Initial prototype
-V0.2
  - Fix silkscreen marking of current sensitivity (20A/V -> 100 A/V)
  - Fix silkscreen marking of diode polarity
  - Fix PJA3463_R1 footprint of reverse polarity protection
  - Fix MABAES0060 (Balun) footprint
  - Remove 2k resistor after schottky diode in the charge loop for better reverse polarity protection
  - Increase charging resistor to 47k
  - Remove HV buffer capacitor
  - Use the enable switch to switch the input voltage, not the enable signal. This prevents the output from floating at Vin when switched off.
  - Add a transistor buffer stage to the trigger circuit
  - Increase operating voltage to 320V by adding a second output multiplier stage
  - Adjust feedback voltage divider for new ouput voltage range
  - Add teardrops to all traces
  - Select smaller rectifier diode

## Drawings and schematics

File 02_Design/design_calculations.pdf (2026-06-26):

## LT8365 DCDC Boost Converter

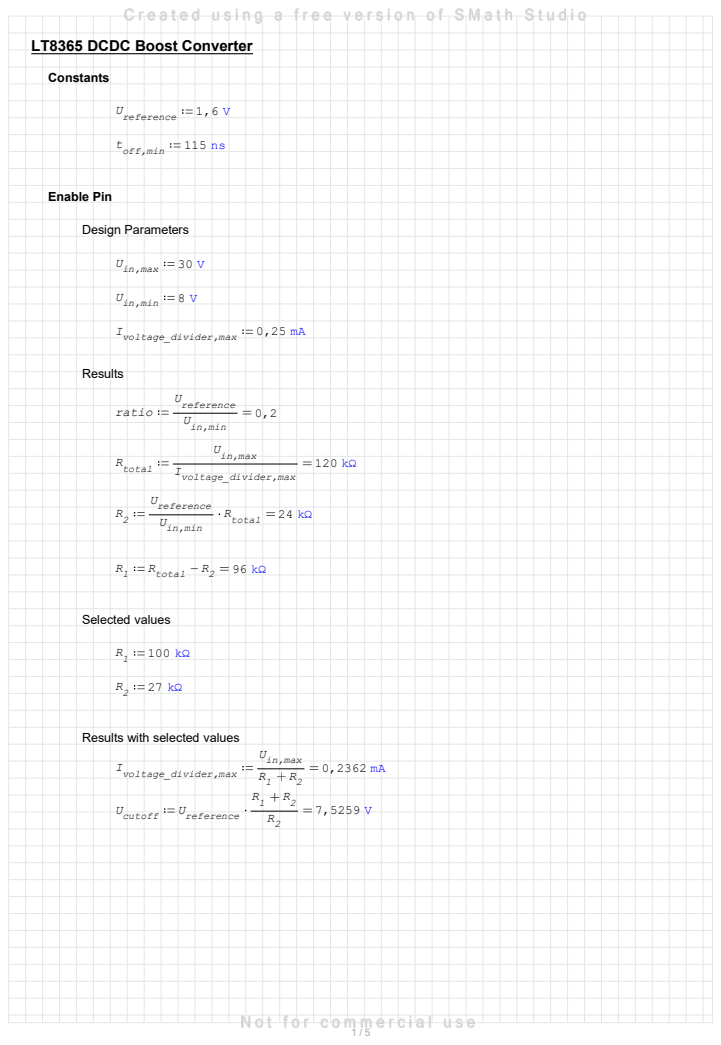
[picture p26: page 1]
Constants; U 1,6 V reference; 115 ns off,min; Enable Pin; Design Parameters; U 30 V in,max; U 8 V in,min; I 0,25 mA voltage_divider,max; Results; Uin,min; Ureference ratio; Ivoltage_divider,max; Uin,max; Rtotal; R 24 kΩ U total in,min; Ureference; Rtotal R1; Selected values; Ureference Ucutoff

Results with selected values

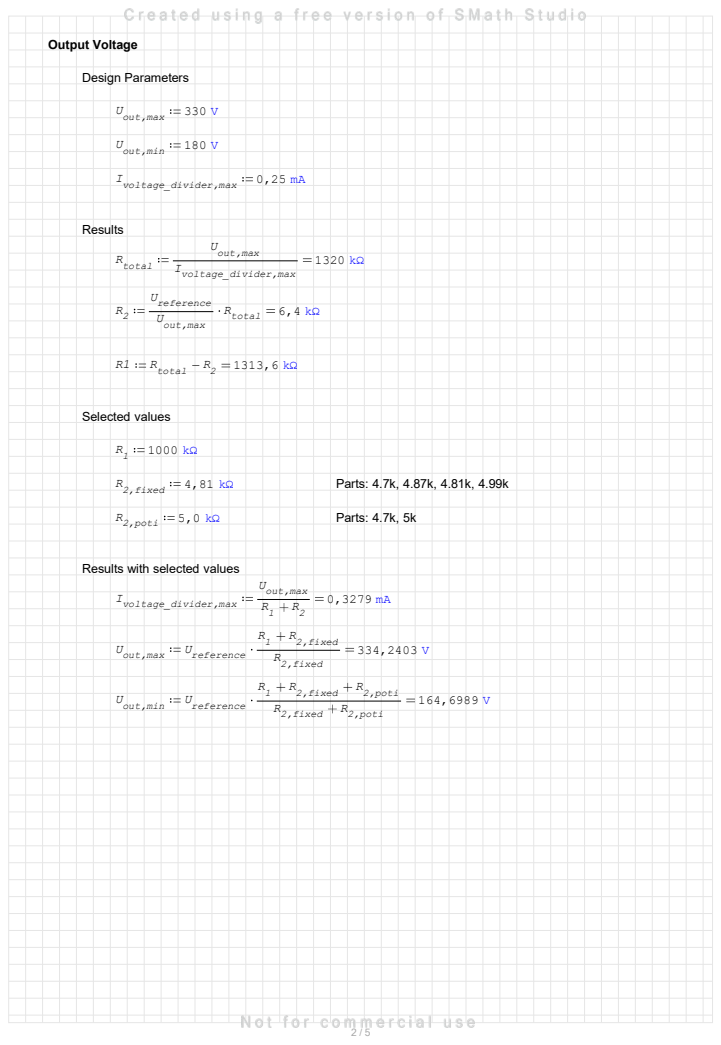
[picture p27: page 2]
Output Voltage; Design Parameters; U 330 V out,max; U 180 V out,min; I 0,25 mA voltage_divider,max; Results; Ivoltage_divider,max; Uout,max; Rtotal; R 6,4 kΩ U total out,max; Ureference; Rtotal R1; Selected values; 4,81 kΩ 2,fixed; Parts: 4.7k, 4.87k, 4.81k, 4.99k; 5,0 kΩ 2,poti; Parts: 4.7k, 5k; R2,fixed; R2,fixed R1; R2,poti R2,fixed; R2,poti R2,fixed R1

Results with selected values

Ureference Uout,max

Ureference Uout,min

### R 130 kΩ T

### 1 kHz 330,0109 kHz

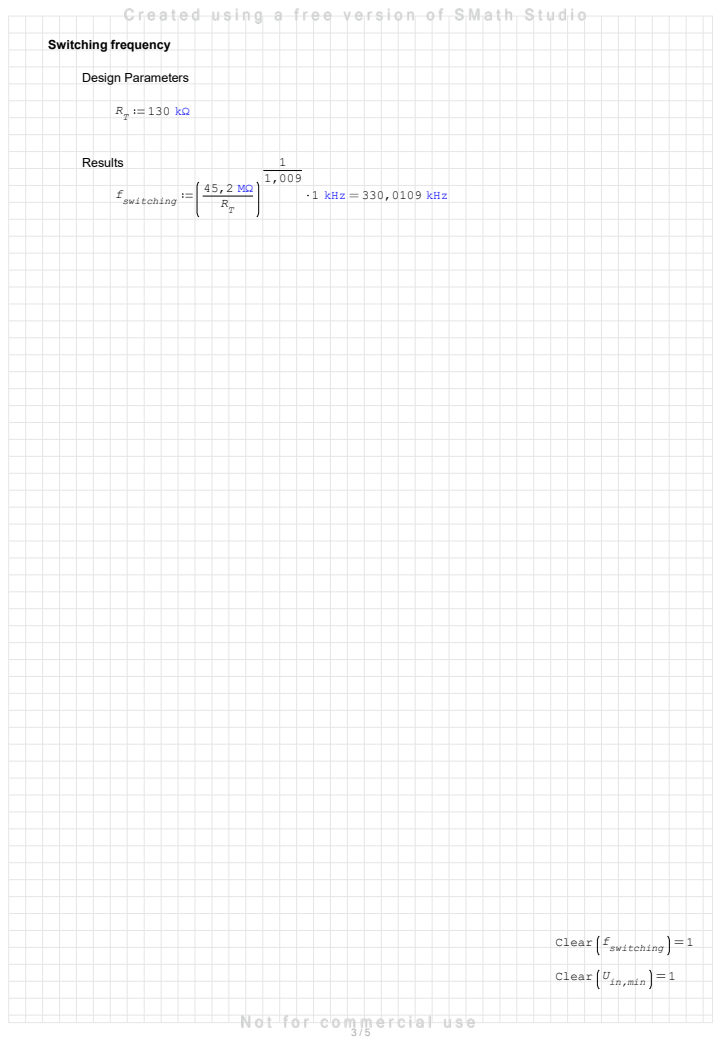
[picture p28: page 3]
Switching frequency; Design Parameters; Results; 45,2 MΩ fswitching; Clear; 1 switching; 1 in,min

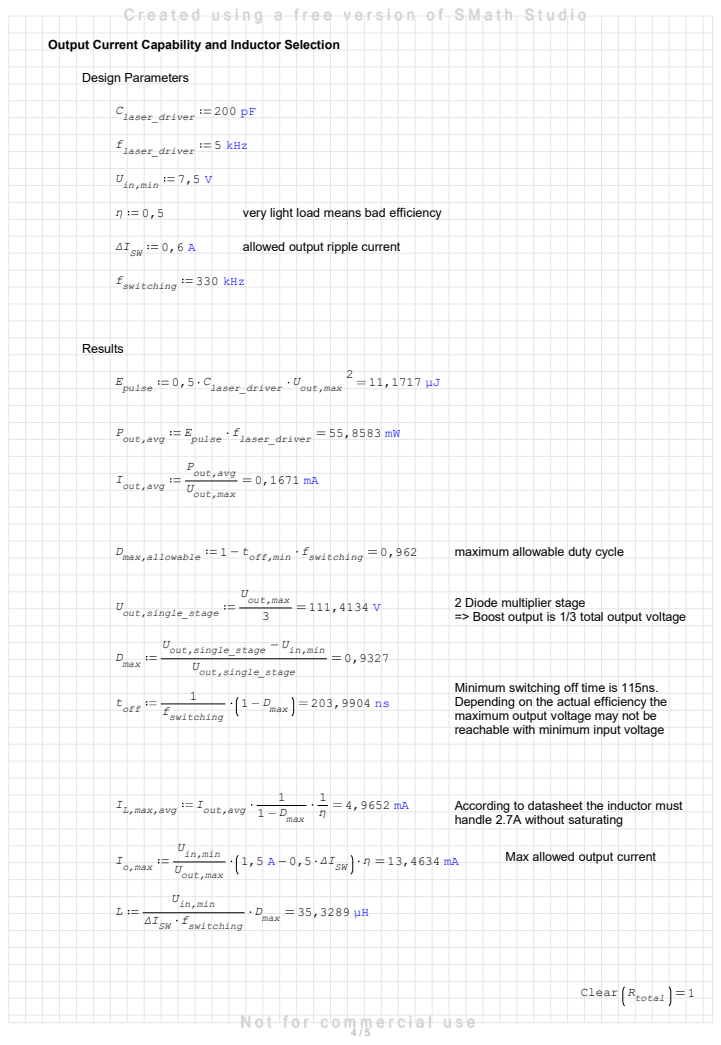
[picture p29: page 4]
Design Parameters; C 200 pF laser_driver; 5 kHz laser_driver; U 7,5 V in,min; very light load means bad efficiency; allowed output ripple current; 330 kHz switching; Results; Uout,max Claser_driver E; 0,5 pulse; 55,8583 mW laser_driver Epulse Pout,avg; Uout,max; Pout,avg; Iout,avg; 0,962 switching toff,min D; 1 max,allowable; maximum allowable duty cycle; Uout,single_stage; Dmax; D 203,9904 ns max 1; fswitching; toff; Dmax 1; Iout,avg IL,max,avg; According to datasheet the inductor must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

Output Current Capability and Inductor Selection

2 Diode multiplier stage
=> Boost output is 1/3 total output voltage

Uin,min Uout,single_stage

Minimum switching off time is 115ns.
Depending on the actual efficiency the
maximum output voltage may not be
reachable with minimum input voltage

handle 2.7A without saturating

Max allowed output current

### I 0,5 mA LED

668,4807 kΩ

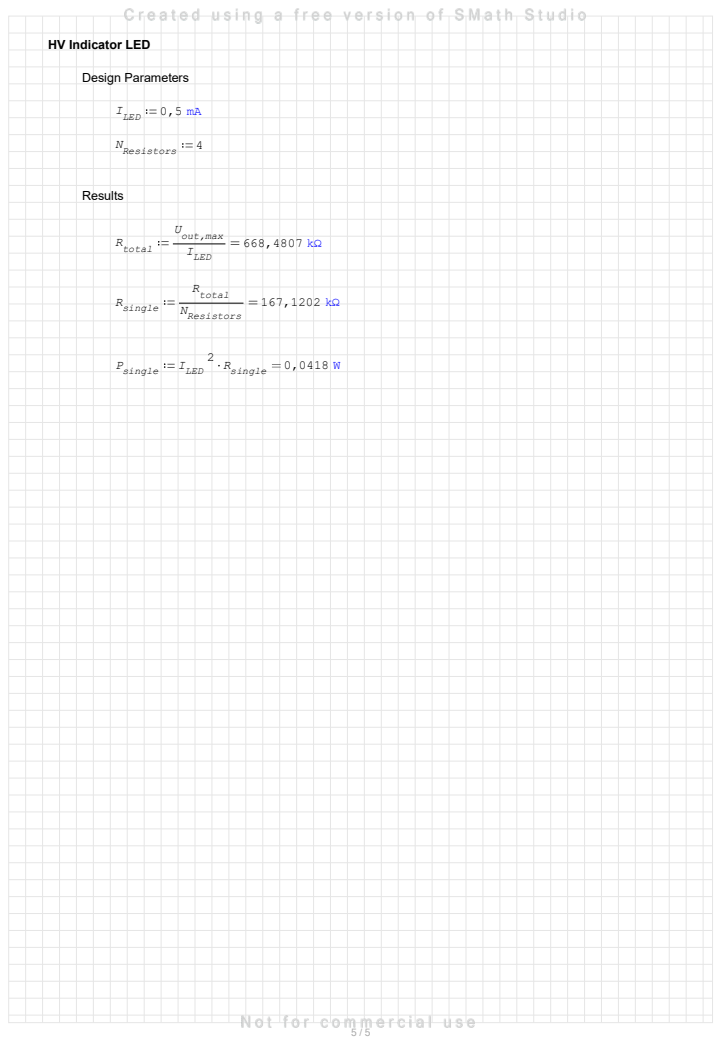
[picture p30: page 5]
Design Parameters; N 4 Resistors; Results; ILED; Uout,max; Rtotal; NResistors; Rsingle; R 0,0418 W single; ILED Psingle

HV Indicator LED

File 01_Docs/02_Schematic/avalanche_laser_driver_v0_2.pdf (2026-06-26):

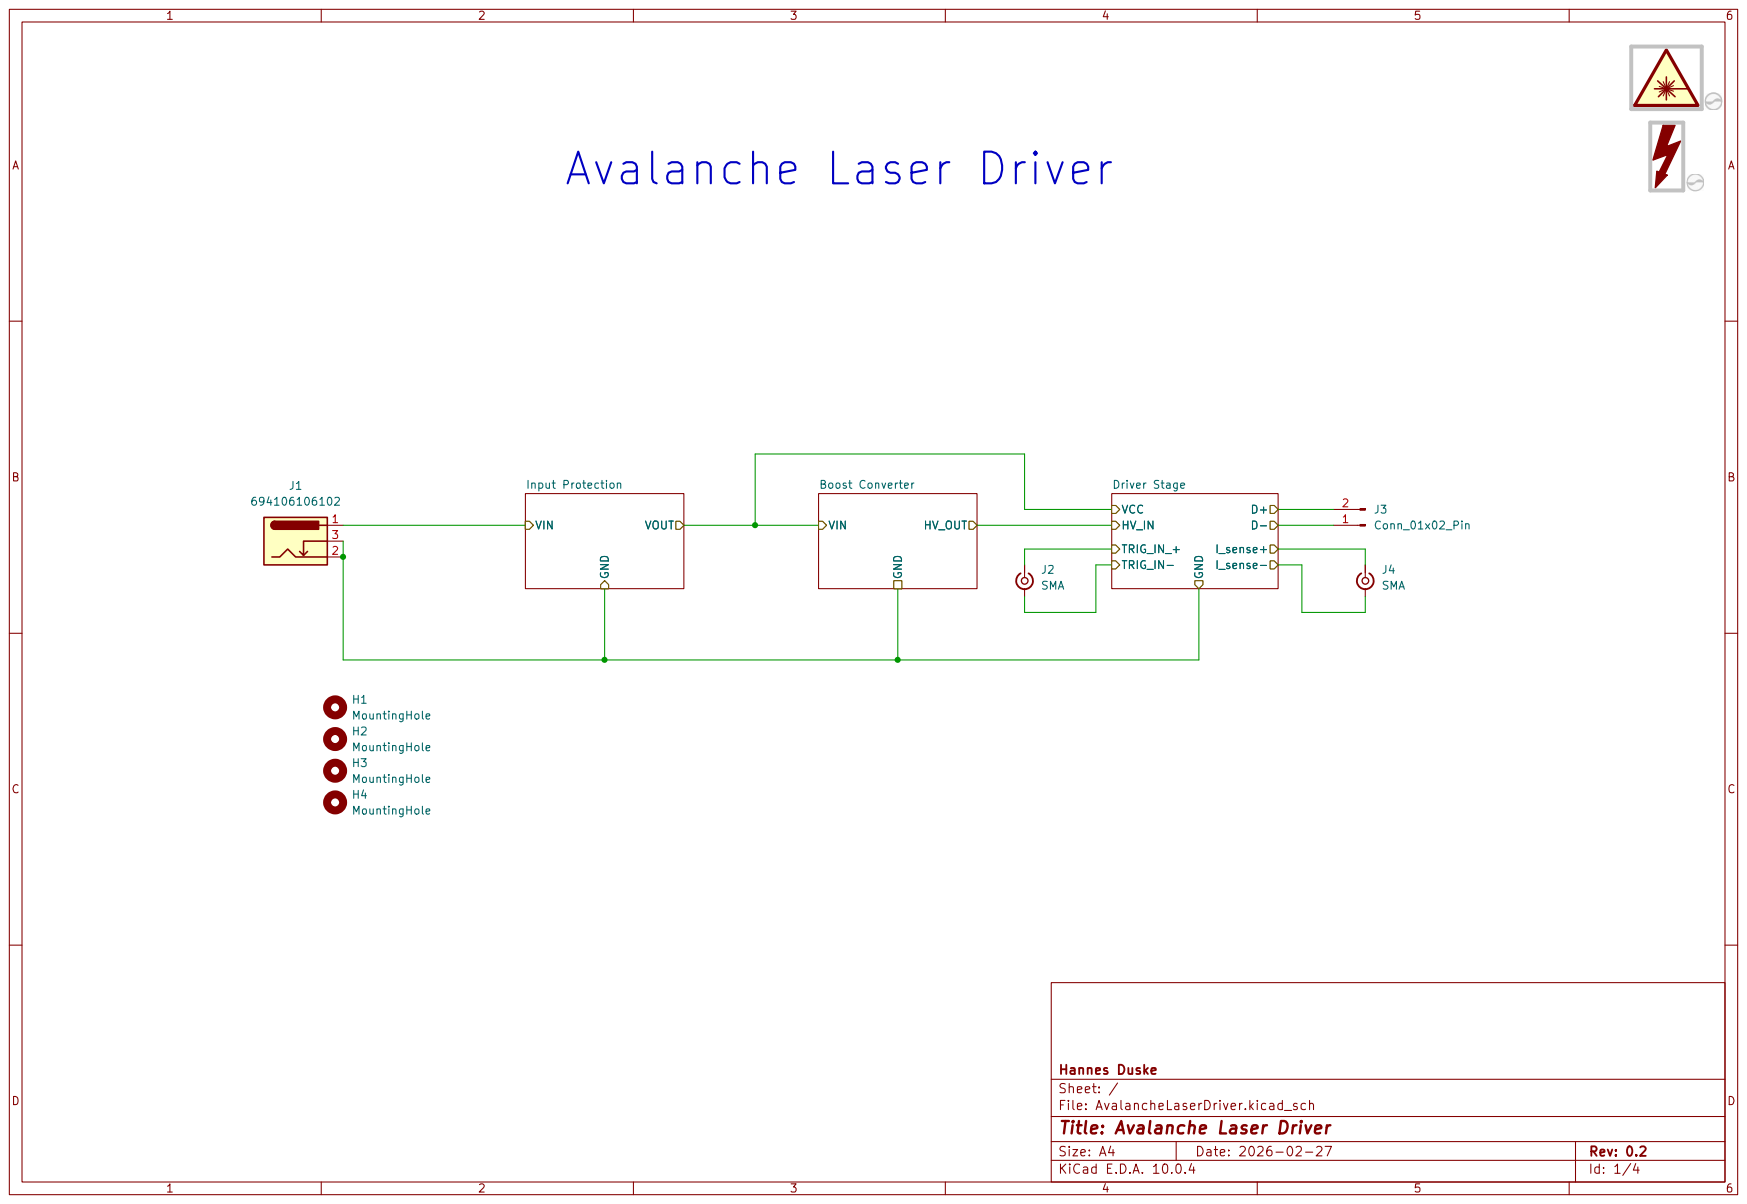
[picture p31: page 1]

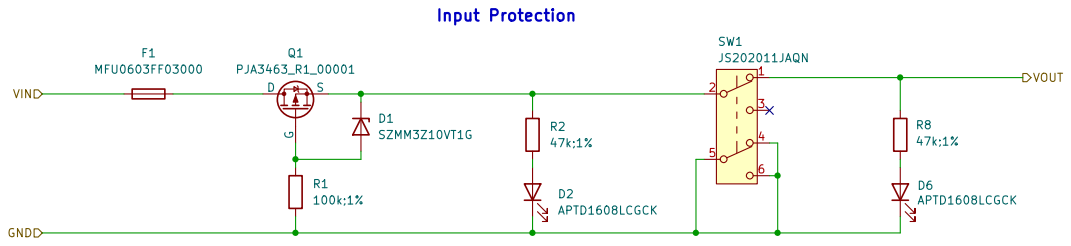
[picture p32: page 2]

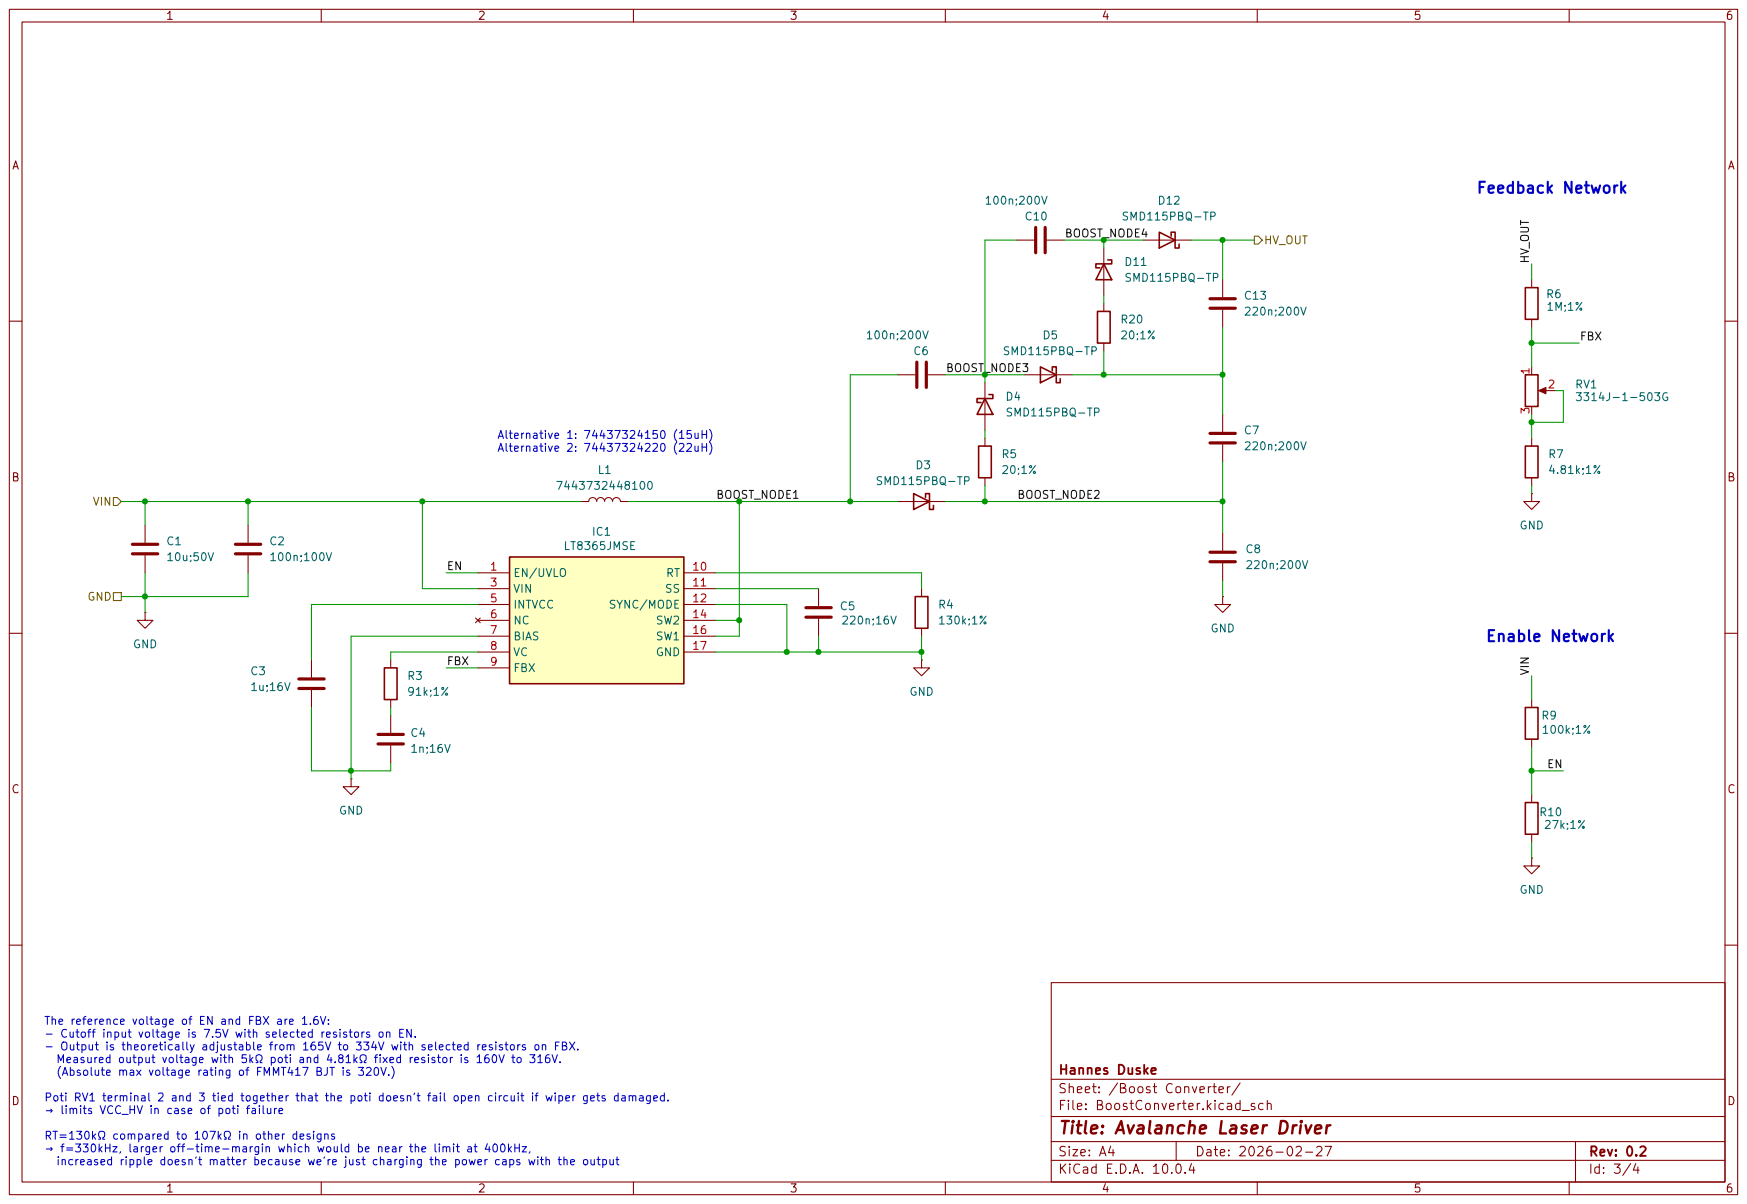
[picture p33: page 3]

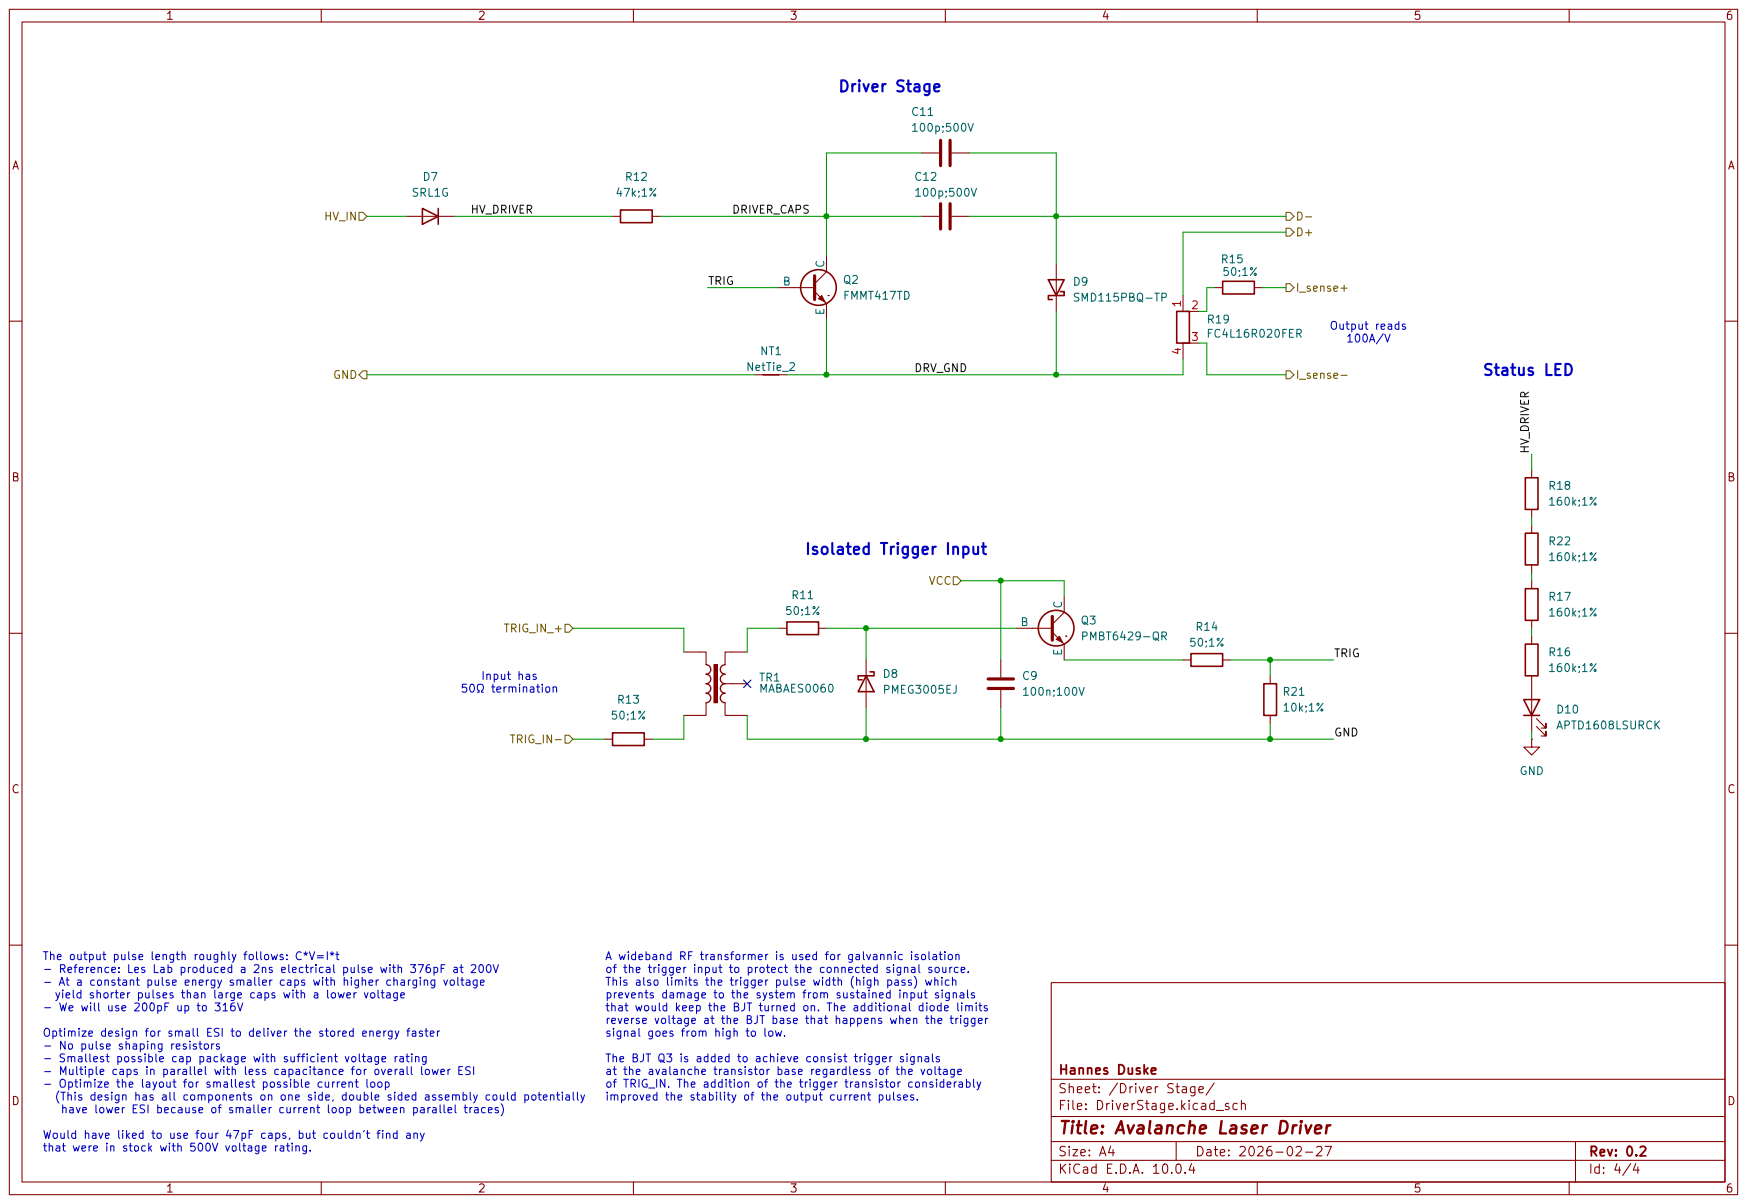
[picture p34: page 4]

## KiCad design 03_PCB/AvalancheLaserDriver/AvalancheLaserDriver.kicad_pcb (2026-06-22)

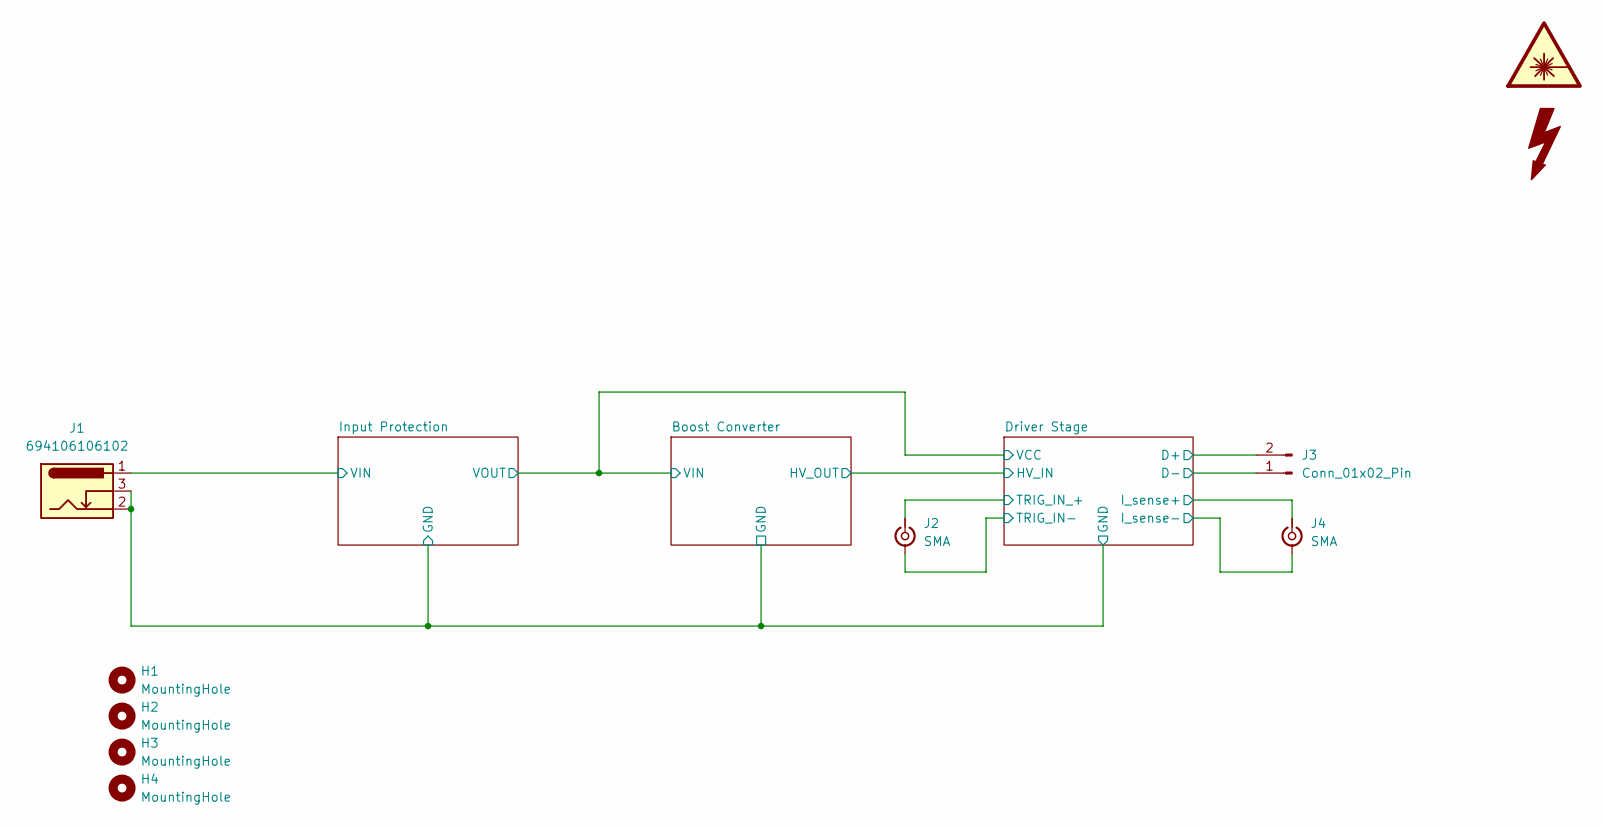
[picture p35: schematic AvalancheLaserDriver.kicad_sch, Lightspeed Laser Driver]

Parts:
H1, H2, H3, H4: MountingHole; MountingHole_3.2mm_M3
J1: 694106106102; BarrelJack_Wuerth_694106106102_2.0x5.5mm
J2, J4: SMA; SMA_Wurth_60312002114503_Vertical
J3: Conn_01x02_Pin; R_0815_2038Metric_Pad1.20x4.05mm_HandSolder

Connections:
/Driver Stage/D+: J3.2; also elsewhere on the board
/Driver Stage/D-: J3.1; also elsewhere on the board
/Driver Stage/I_sense+: J4.1 (In); also elsewhere on the board
/Driver Stage/I_sense-: J4.2 (Ext); also elsewhere on the board
/Driver Stage/TRIG_IN-: J2.2 (Ext); also elsewhere on the board
/Driver Stage/TRIG_IN_+: J2.1 (In); also elsewhere on the board
/Input Protection/VIN: J1.1; also elsewhere on the board
GND: J1.2, J1.3; also elsewhere on the board

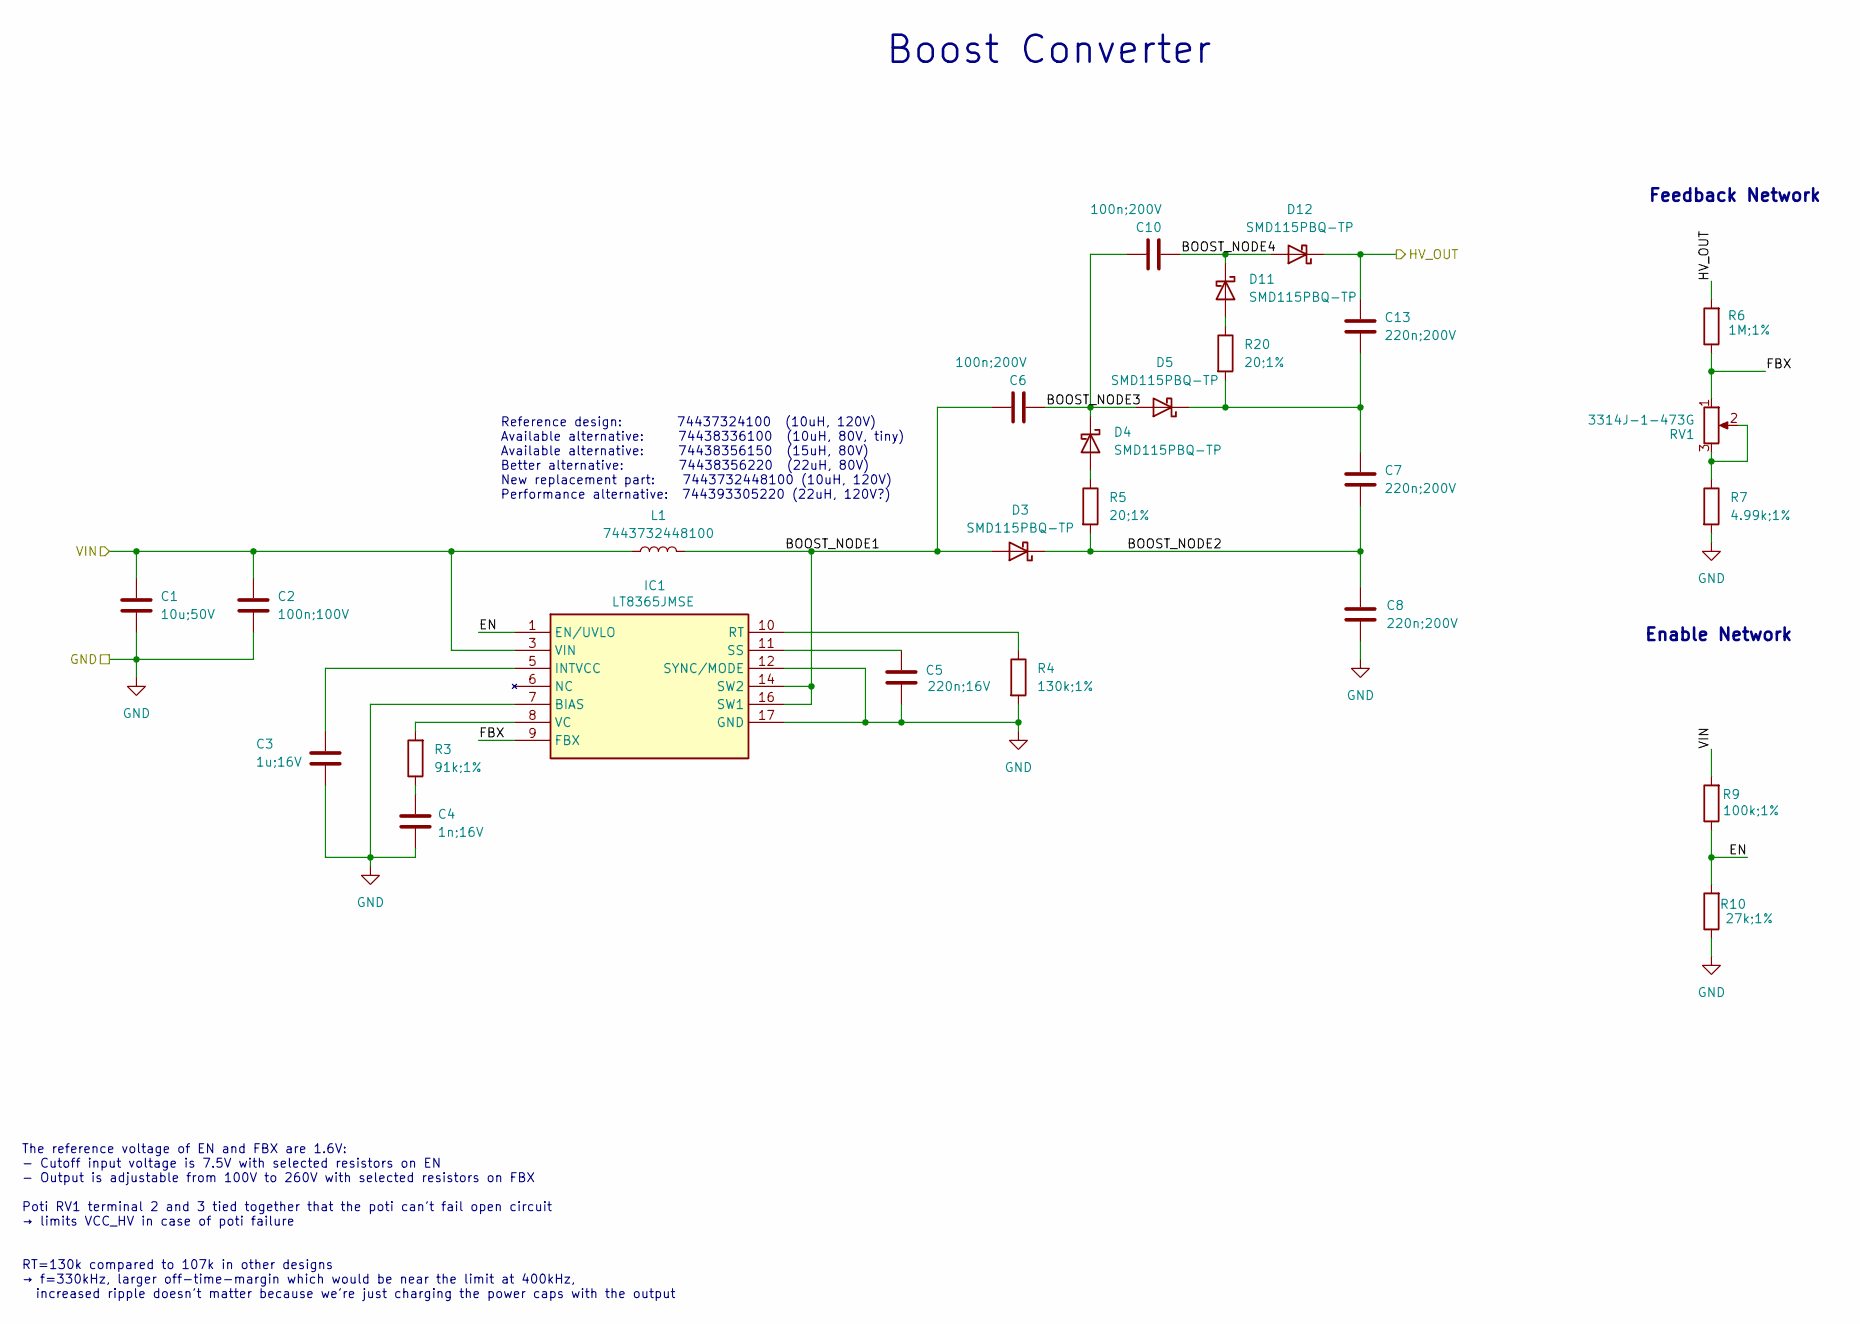
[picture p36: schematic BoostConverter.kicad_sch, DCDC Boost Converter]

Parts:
C1: 10u;50V; C_1206_3216Metric
C2: 100n;100V; C_0603_1608Metric
C3: 1u;16V; C_0603_1608Metric
C4: 1n;16V; C_0603_1608Metric
C5: 220n;16V; C_0603_1608Metric
C6, C10: 100n;200V; C_0805_2012Metric
C7, C8, C13: 220n;200V; C_1206_3216Metric
D3, D4, D5, D11, D12: SMD115PBQ-TP; D_SOD-323HE
IC1: LT8365JMSE; Analog_MSOP-12-16-1EP_3x4.039mm_P0.5mm_EP1.651x2.845mm; Mouser Part Number 584-LT8365JMSE
L1: 7443732448100; L_Wurth_WE-LQSH-4020
R3: 91k;1%; R_0603_1608Metric
R4: 130k;1%; R_0603_1608Metric
R5, R20: 20;1%; R_0603_1608Metric
R6: 1M;1%; R_0603_1608Metric
R7: 4.99k;1%; R_0603_1608Metric
R9: 100k;1%; R_0603_1608Metric
R10: 27k;1%; R_0603_1608Metric
RV1: 3314J-1-473G; Potentiometer_Bourns_3314J_Vertical

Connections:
/Boost Converter/BOOST_NODE1: C6.1, D3.2 (A), IC1.14 (SW2), IC1.16 (SW1), L1.2
/Boost Converter/BOOST_NODE2: C7.1, C8.2, D3.1 (K), R5.2
/Boost Converter/BOOST_NODE3: C6.2, C10.1, D4.1 (K), D5.2 (A)
/Boost Converter/BOOST_NODE4: C10.2, D11.1 (K), D12.2 (A)
/Boost Converter/EN: IC1.1 (EN/UVLO), R9.1, R10.2
/Boost Converter/FBX: IC1.9 (FBX), R6.1, RV1.1
/Boost Converter/HV_OUT: C13.2, D12.1 (K), R6.2; also elsewhere on the board
/Boost Converter/VIN: C1.2, C2.2, IC1.3 (VIN), L1.1, R9.2; also elsewhere on the board
GND: C1.1, C2.1, C3.1, C4.1, C5.1, C8.1, IC1.7 (BIAS), IC1.12 (SYNC/MODE), IC1.17 (GND), R4.2, R7.2, R10.1; also elsewhere on the board
unnamed: C4.2, R3.1
unnamed: D4.2 (A), R5.1
unnamed: C7.2, C13.1, D5.1 (K), R20.2
unnamed: D11.2 (A), R20.1
unnamed: C3.2, IC1.5 (INTVCC)
unnamed: IC1.10 (RT), R4.1
unnamed: C5.2, IC1.11 (SS)
unnamed: IC1.8 (VC), R3.2
unnamed: R7.1, RV1.2, RV1.3

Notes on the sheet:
Enable Network
The reference voltage of EN and FBX are 1.6V: - Cutoff input voltage is 7.5V with selected resistors on EN - Output is adjustable from 100V to 260V with selected resistors on FBX Poti RV1 terminal 2 and 3 tied together that the poti can't fail open circuit → limits VCC_HV in case of poti failure RT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
Reference design: 74437324100 (10uH, 120V) Available alternative: 74438336100 (10uH, 80V, tiny) Available alternative: 74438356150 (15uH, 80V) Better alternative: 74438356220 (22uH, 80V) New replacement part: 7443732448100 (10uH, 120V) Performance alternative: 744393305220 (22uH, 120V?)
Boost Converter
Feedback Network

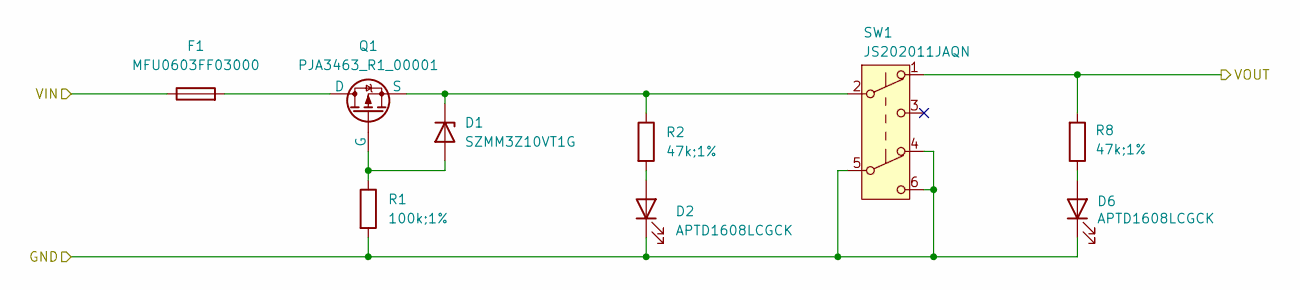
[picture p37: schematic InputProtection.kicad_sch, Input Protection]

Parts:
D1: SZMM3Z10VT1G; D_SOD-323
D2, D6: APTD1608LCGCK; LED_0603_1608Metric
F1: MFU0603FF03000; Fuse_0603_1608Metric
Q1: PJA3463_R1_00001; SOT-23
R1: 100k;1%; R_0603_1608Metric
R2, R8: 47k;1%; R_0603_1608Metric
SW1: JS202011JAQN; SW_DPDT_CK_JS202011JCQN

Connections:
/Boost Converter/VIN: R8.2, SW1.1 (A); also elsewhere on the board
/Input Protection/VIN: F1.1; also elsewhere on the board
GND: D2.1 (K), D6.1 (K), R1.2, SW1.4 (A), SW1.5 (B), SW1.6 (C); also elsewhere on the board
unnamed: D1.2 (A), Q1.1 (G), R1.1
unnamed: D1.1 (K), Q1.2 (S), R2.1, SW1.2 (B)
unnamed: D2.2 (A), R2.2
unnamed: D6.2 (A), R8.1
unnamed: F1.2, Q1.3 (D)

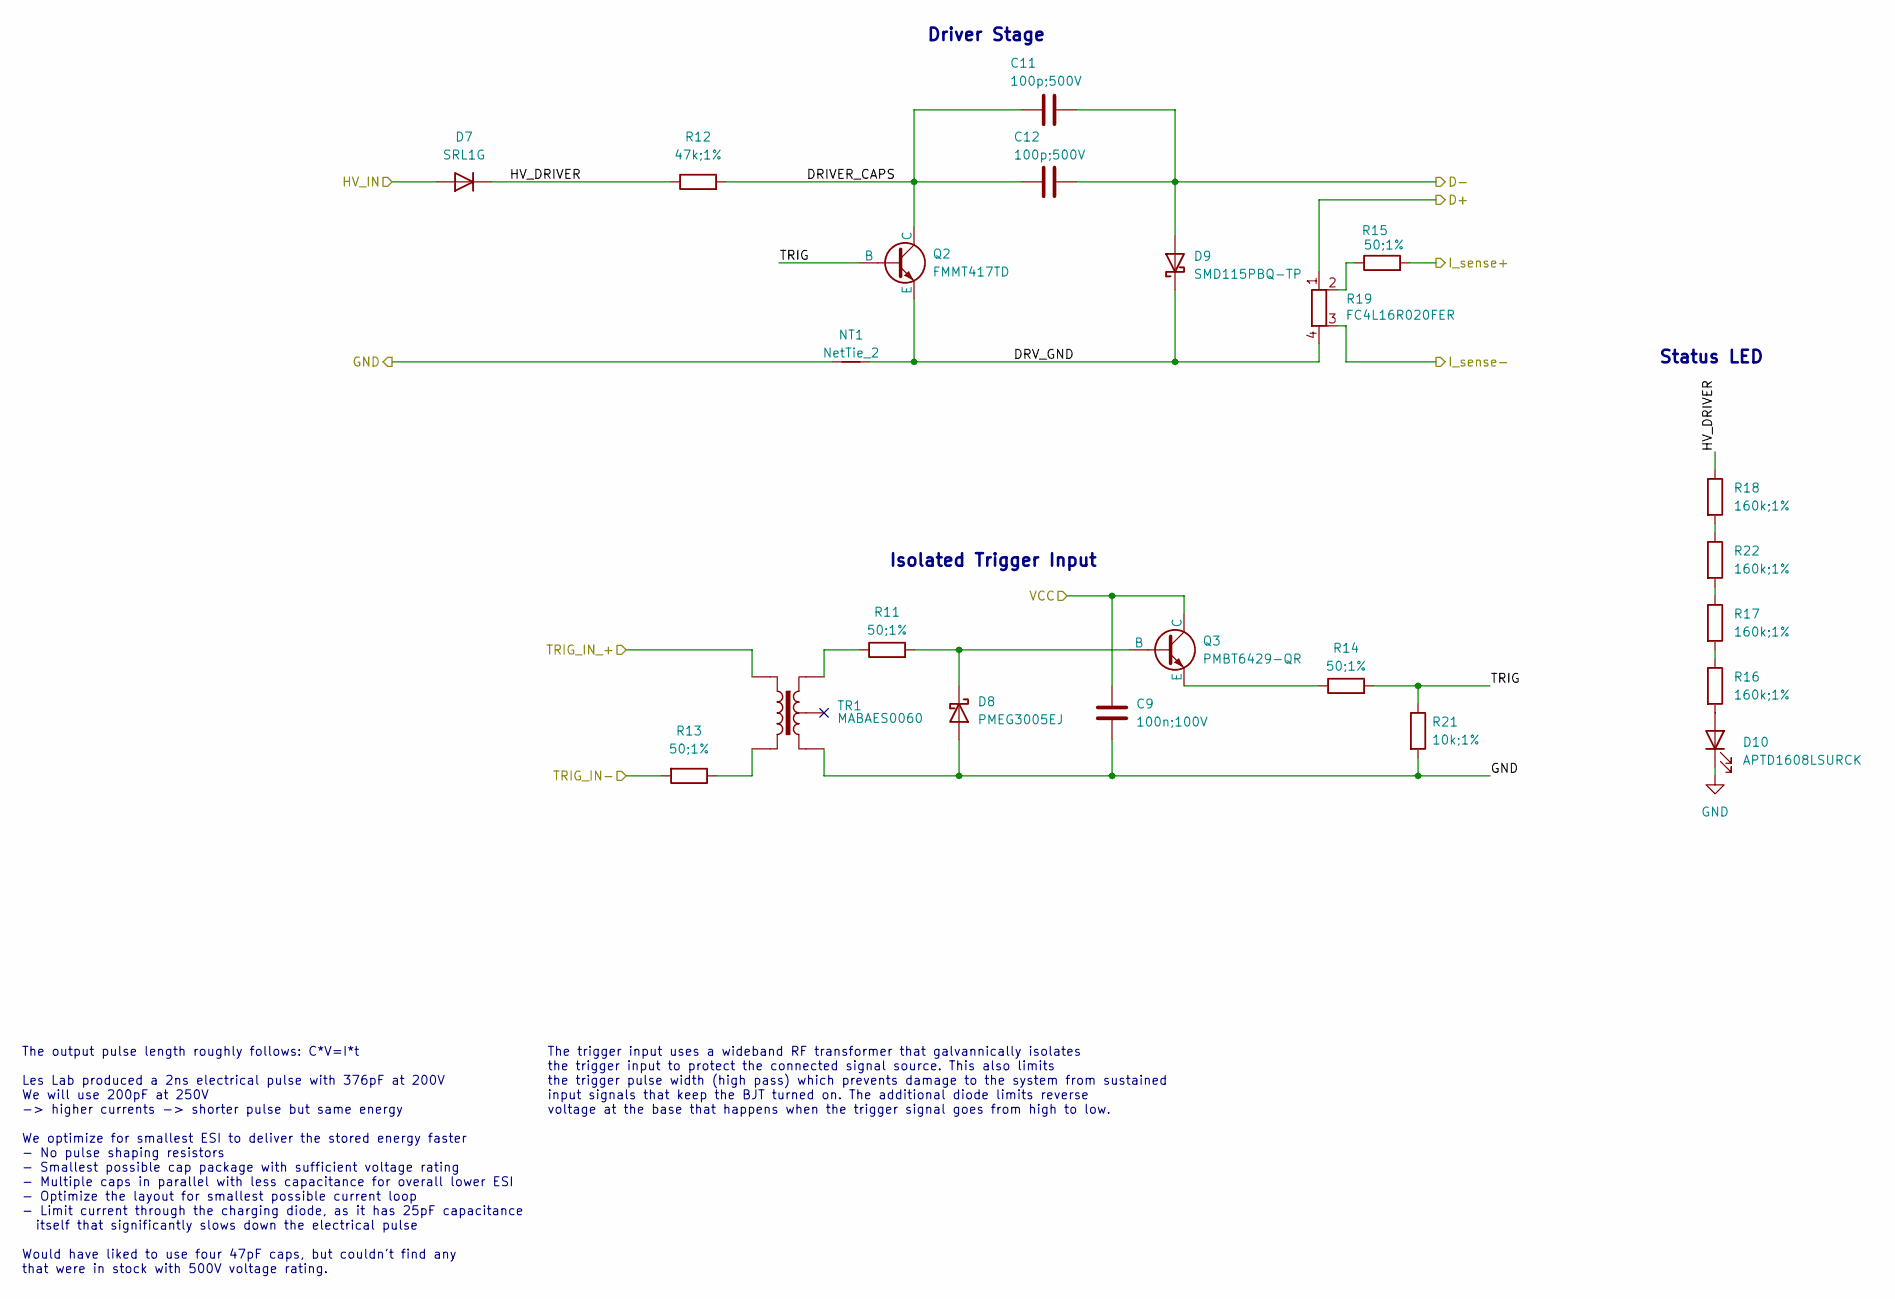
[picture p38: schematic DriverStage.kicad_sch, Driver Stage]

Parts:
C9: 100n;100V; C_0603_1608Metric
C11, C12: 100p;500V; C_0603_1608Metric
D7: SRL1G; D_SOD-323HE
D8: PMEG3005EJ; D_SOD-323
D9: SMD115PBQ-TP; D_SOD-323HE
D10: APTD1608LSURCK; LED_0603_1608Metric
NT1: NetTie_2; NetTie-2_THT_Pad0.3mm
Q2: FMMT417TD; TSOT-23
Q3: PMBT6429-QR; TSOT-23
R11, R13, R14, R15: 50;1%; R_0603_1608Metric
R12: 47k;1%; R_0603_1608Metric
R16, R17, R18, R22: 160k;1%; R_0603_1608Metric
R19: FC4L16R020FER; FC4L16
R21: 10k;1%; R_0603_1608Metric
TR1: MABAES0060; Transformer_MACOM_SM-22

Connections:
/Boost Converter/HV_OUT: D7.2 (A); also elsewhere on the board
/Boost Converter/VIN: C9.2, Q3.3 (C); also elsewhere on the board
/Driver Stage/D+: R19.1; also elsewhere on the board
/Driver Stage/D-: C11.2, C12.2, D9.2 (A); also elsewhere on the board
/Driver Stage/DRIVER_CAPS: C11.1, C12.1, Q2.3 (C), R12.2
/Driver Stage/DRV_GND: D9.1 (K), NT1.2, Q2.2 (E), R19.4
/Driver Stage/HV_DRIVER: D7.1 (K), R12.1, R18.1
/Driver Stage/I_sense+: R15.2; also elsewhere on the board
/Driver Stage/I_sense-: R19.3; also elsewhere on the board
/Driver Stage/TRIG: Q2.1 (B), R14.2, R21.1
/Driver Stage/TRIG_IN-: R13.2; also elsewhere on the board
/Driver Stage/TRIG_IN_+: TR1.2; also elsewhere on the board
GND: C9.1, D8.2 (A), D10.1 (K), NT1.1, R21.2, TR1.5; also elsewhere on the board
unnamed: D8.1 (K), Q3.1 (B), R11.2
unnamed: D10.2 (A), R16.2
unnamed: Q3.2 (E), R14.1
unnamed: R11.1, TR1.3
unnamed: R13.1, TR1.1
unnamed: R15.1, R19.2
unnamed: R16.1, R17.2
unnamed: R17.1, R22.2
unnamed: R18.2, R22.1

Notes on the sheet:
The trigger input uses a wideband RF transformer that galvannically isolates the trigger input to protect the connected signal source. This also limits the trigger pulse width (high pass) which prevents damage to the system from sustained input signals that keep the BJT turned on. The additional di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
Isolated Trigger Input
Status LED
The output pulse length roughly follows: C*V=I*t Les Lab produced a 2ns electrical pulse with 376pF at 200V We will use 200pF at 250V -> higher currents -> shorter pulse but same energy We optimize for smallest ESI to deliver the stored energy faster - No pulse shaping resistors - Smallest possible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
Driver Stage

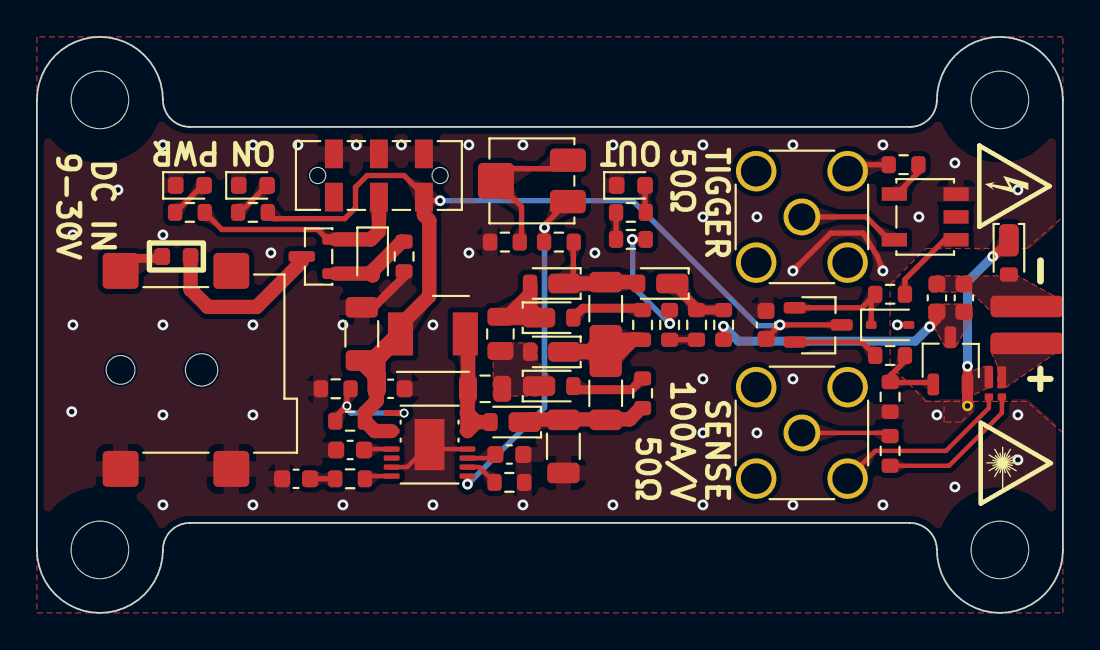
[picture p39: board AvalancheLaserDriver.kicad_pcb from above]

Board: 2 copper layers, 57.0 x 32.0 mm, 65 parts (0 on the bottom side), 43 nets.

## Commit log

2026-06-22 feat(pcb): intital pcb layout
    [BoostConverter.kicad_sch, DriverStage.kicad_sch, LightspeedLaserDriver.kicad_pcb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]
2026-06-22 feat(simulation): add a lt8365 simulation including the led driver stage
2026-06-22 feat(pcb): add peripherals to PCB
    [BoostConverter.kicad_sch, LightspeedLaserDriver.kicad_pcb, LightspeedLaserDriver.kicad_sch]
2026-06-22 feat(pcb): route all traces
    [BoostConverter.kicad_sch, DriverStage.kicad_sch, LightspeedLaserDriver.kicad_pcb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]
2026-06-22 feat(pcb): laser driver layout draft finished, add high voltage indicator LED and discharge path
    [BoostConverter.kicad_sch, DriverStage.kicad_sch, LightspeedLaserDriver.kicad_pcb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]
2026-06-22 feat(pcb): improve the design draft
    [BoostConverter.kicad_sch, DriverStage.kicad_sch, LightspeedLaserDriver.kicad_pcb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]
2026-06-22 feat(pcb): laser driver V0.1 as ordered on 08.03.2026
    [LightspeedLaserDriver-B_Cu.gbl, LightspeedLaserDriver-B_Mask.gbs, LightspeedLaserDriver-B_Paste.gbp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]
2026-06-22 chore: restructure desing files in repo
    [BoostConverter.kicad_sch, DriverStage.kicad_sch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]
2026-06-22 feat(pcb): add changelog
2026-06-22 refactor(pcb): rename laser driver PCB to AvalancheLaserDriver
    [AvalancheLaserDriver-V0.1.csv, AvalancheLaserDriver.kicad_pcb, AvalancheLaserDriver.kicad_sch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]
2026-06-22 feat(pcb): edit component values after assembling first prototype
    [AvalancheLaserDriver.kicad_pcb, AvalancheLaserDriver.kicad_sch, DriverStage.kicad_sch]
2026-06-22 feat(pcb): update laser driver circuit after first iteration
    [AvalancheLaserDriver.kicad_pcb, AvalancheLaserDriver.kicad_sch, BoostConverter.kicad_sch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]
2026-06-22 feat(pcb): Increase operating voltage to 320V
    [AvalancheLaserDriver.kicad_pcb, BoostConverter.kicad_sch, DriverStage.kicad_sch]
2026-06-22 feat(pcb): finalize layout of PCB V0.2
    [AvalancheLaserDriver.kicad_pcb, DriverStage.kicad_sch]
2026-06-22 feat(pcb): laser driver V0.2 as ordered on 08.04.2026
    [AvalancheLaserDriver.csv, AvalancheLaserDriver.kicad_pcb, AvalancheLaserDriver.kicad_sch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]
2026-06-22 feat(pcb): add assembly files for V0.2
    [AvalancheLaserDriver.kicad_pcb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]
2026-06-22 chore(pcb): update schematic with tuned component values and update notes
    [AvalancheLaserDriver.kicad_sch, BoostConverter.kicad_sch, DriverStage.kicad_sch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]
2026-06-22 docs(pcb): update changelog
2026-06-27 docs: document current sense output
2026-07-10 feat(cover): add 3D printable protective cover for the driver
    [pcb_cover.3mf, pcb_cover_text.3mf]
2026-10-21 docs: document the optical light output of the tested diodes
